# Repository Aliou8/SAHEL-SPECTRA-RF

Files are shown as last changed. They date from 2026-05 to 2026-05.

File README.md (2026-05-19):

# SAHEL-CUBESAT: An Experimental Educational CubeSat 
# Project work in progress

This project aims to develop a complete experimental CubeSat for educational purposes. It is based on an STM32H7 MCU for data handling and uses two CC1200 radios for communication. The software is developed using a Zephyr-like RTOS.

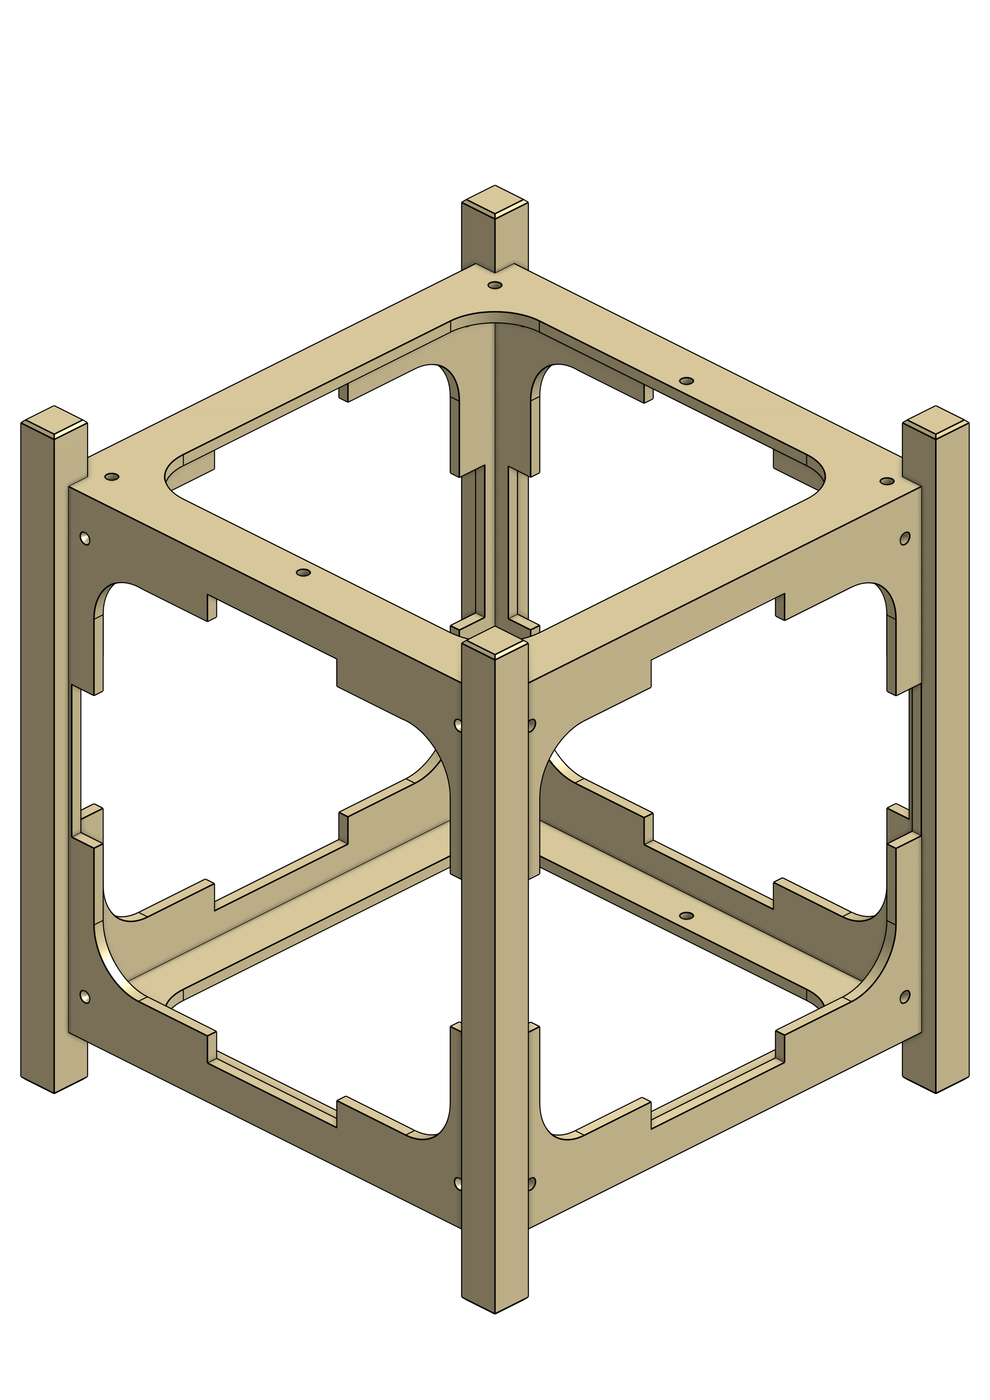
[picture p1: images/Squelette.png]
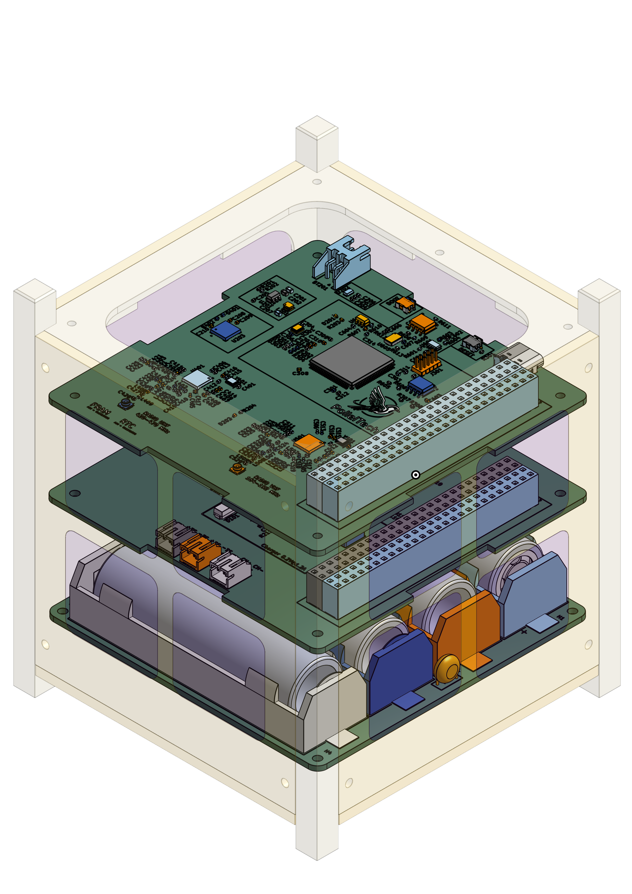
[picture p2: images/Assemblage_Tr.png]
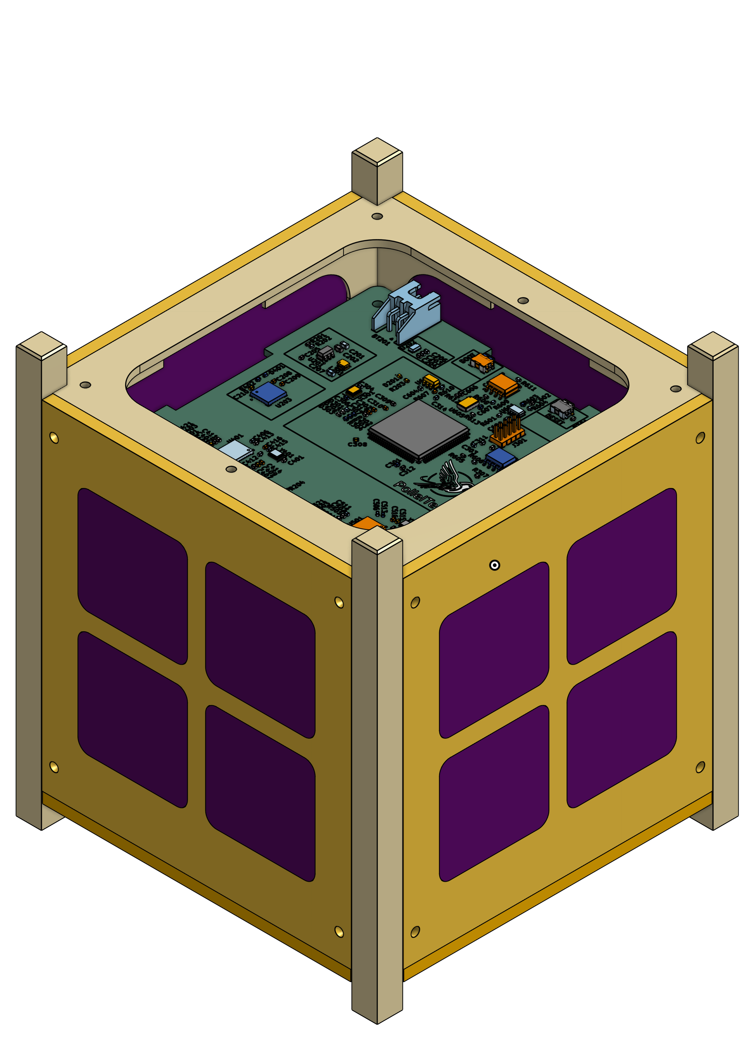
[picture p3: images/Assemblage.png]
<table>  <tr>    <td align="center">      <br>      <b>Mechanical Frame</b>    </td>    <td align="center">      <br>      <b>CubeSat Assembly with PCBs</b>    </td>    <td align="center">      <br>      <b>Complete CubeSat Assembly</b>    </td>  </tr></table>

## Table of Contents

- [Hardware](#hardware)
  - [Structure](#structure)
  - [Electronics](#electronics)
    - [Radio and OBC PCB](#radio-and-obc-pcb)
    - [Solar Panel and Battery PCB](#solar-panel-and-battery-pcb)

- [Software](#software)
  - [System Logic](#system-logic)
  - [Implementation](#implementation)

- [Ground Station Communication](#ground-station-communication)

---

## Hardware

### Structure

The structure was designed according to the specifications using [Onshape](https://cad.onshape.com?utm_source=chatgpt.com). All printable components can be found in this [directory](hardware/structure/).
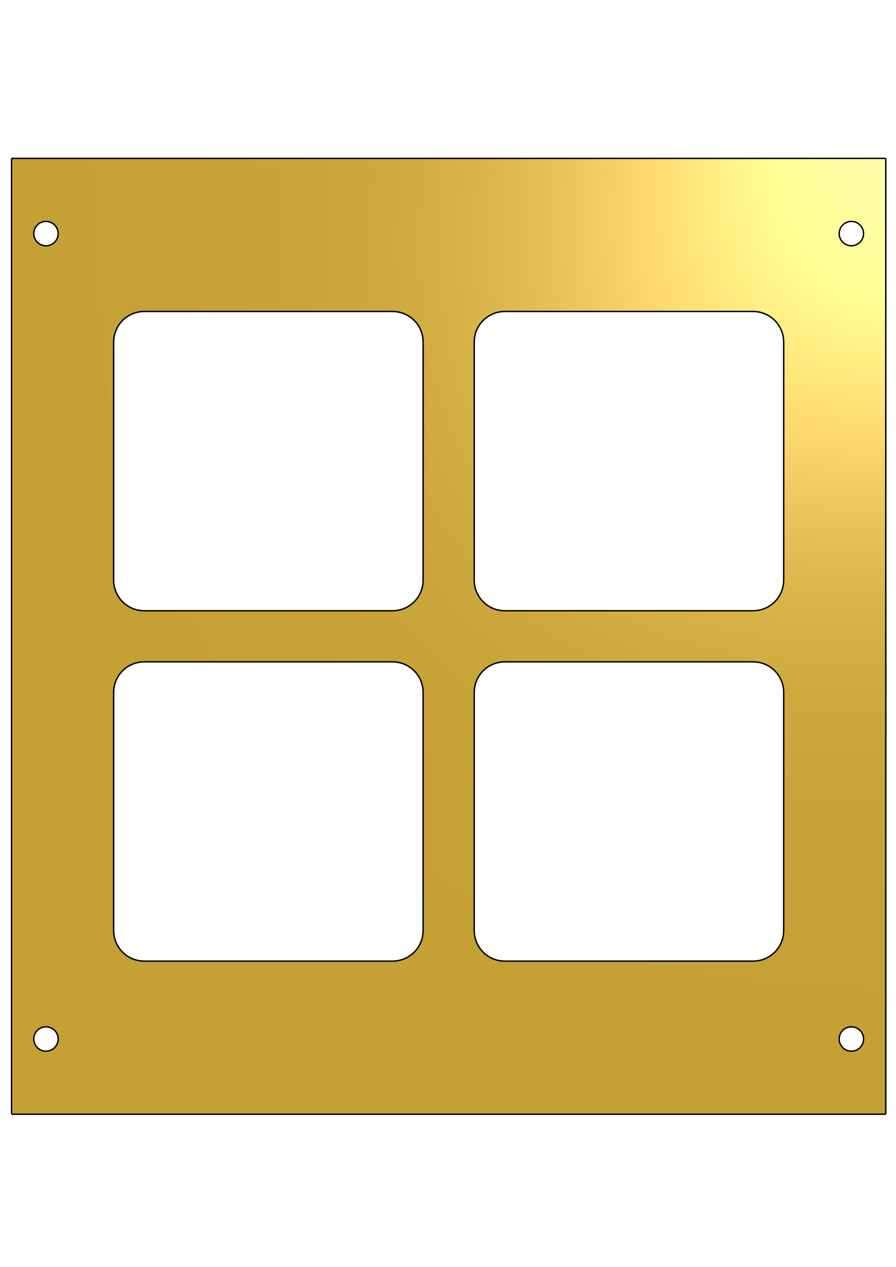
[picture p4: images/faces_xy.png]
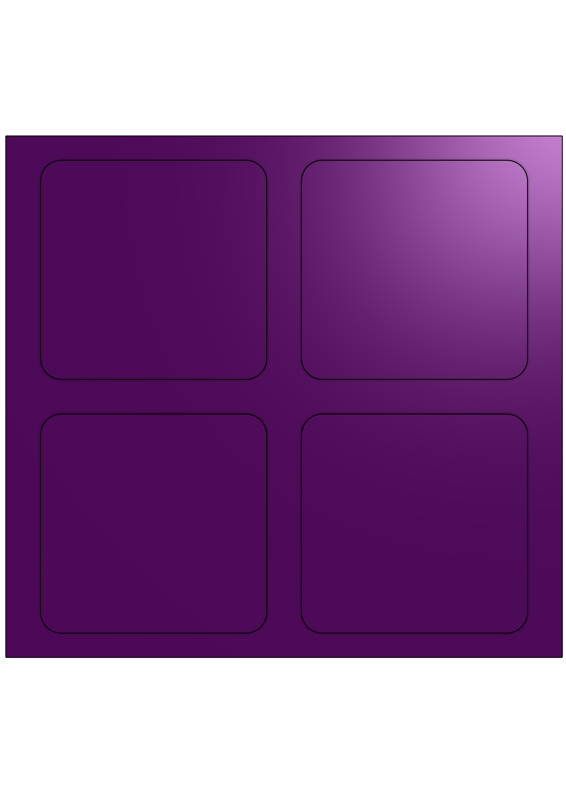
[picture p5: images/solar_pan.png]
<table>  <tr>    <td align="center">      <br>      <b>Mechanical faces X+ X- Y+ Y-</b>    </td>    <td align="center">      <br>      <b>Mechanical faces Z+ Z-</b>    </td>    <td align="center">      <br>      <b> Solar panel</b>    </td>  </tr></table>

---

### Electronics

KiCad is used for the electronic design. The hardware is divided into three parts. The first part includes the radio communication system and the OBC (On-Board Computer) for the CubeSat. The second part consists of a board integrating several sensors and a solar MPPT controller IC.

#### Radio and OBC PCB : Available in: [hardware/sahel_pcb_main](hardware/sahel_pcb_main/)

<table>
  <tr>
    <td align="center">
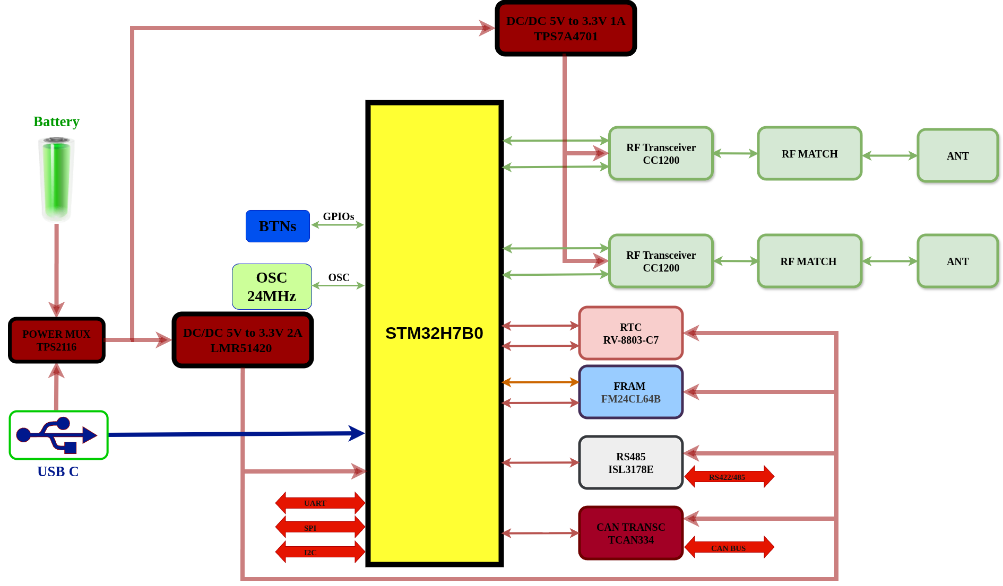
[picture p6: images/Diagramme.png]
      <br>
      <b>Architectural Diagram of the Radio and OBC PCB</b>
    </td>
    <td align="center">
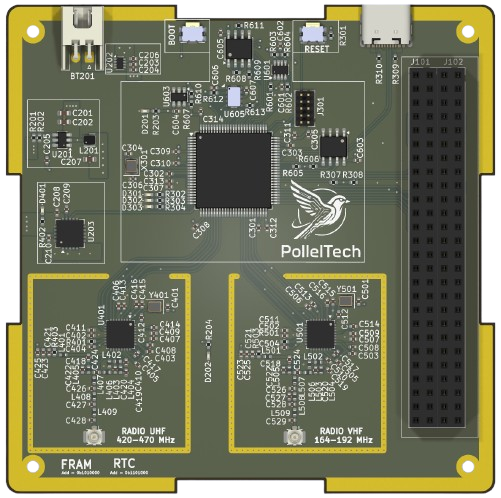
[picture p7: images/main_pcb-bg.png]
      <br>
      <b>Radio and OBC PCB</b>
    </td>
  </tr>
</table>

---

##### Components

###### MCU

**STM32H7B0VBTx**  
High-performance Arm Cortex-M7 MCU with DSP and DP-FPU, 128 KB Flash, 1,376 KB SRAM, up to 280 MHz.

---

###### FRAM — FM24CL64B

| Parameter | Value |
|---|---|
| Memory | 64-Kbit (8K × 8) |
| I2C Address | `0b1010000` |
| SDA (I2C3) | PC9 |
| SCL (I2C3) | PA8 |
| Write Protect | PC5 |

###### Sensors

**Accelerometer, Gyroscope, and Magnetometer: LSM9DS1**  
**Barometer: BMP388**

| Parameter | Value |
|---|---|
| I2C Address (ACC/GYRO) | `0b1101011` |
| I2C Address (MAG) | `0b0011110` |
| I2C Address (BARO) | `0b1110111` |
| SDA (I2C4) | PD13 |
| SCL (I2C4) | PD12 |
| INT_ACC/GYRO | PE8 |
| DRDY_MAG | PE7 |
| DRDY_BARO | PB2 |
---

###### RTC & Temperature Sensor

**RTC: RV-8803-C7**  
**TEMP: TMP100**

| Parameter | Value |
|---|---|
| RTC I2C Address  | `0b0110010` |
| TEMP I2C Address | `0b1001000` |
| SDA (I2C1) | PB7 |
| SCL (I2C1) | PB6 |
| RTC_INT | PB5 |
| RTC_EVI | PB4 |

---

###### CAN Interface: TCAN334G

| Signal | Pin  |
|---|---|
| CAN1_TX | PD1  |
| CAN1_RX | PD0  |
| CAN_SHDN | PA15 |
| CAN_STBY | PD2  |

---

###### RS-485 Interface: ISL3170E

| Signal | Pin  |
|---|---|
| UART2_RX | PD6  |
| UART2_TX | PD5  |
| UART2_EN | PD4  |

---
###### Radio Interface: CC1200

The CC1200 device is a fully integrated single-chip radio transceiver designed for high performance at very low-power and low-voltage operation in cost-effective wireless systems frequency bands at 164–192 MHz, 274–320 MHz, 410–480 MHz, and 820–960 MHz.

**UHF(TX/RX) 420-470 MHz**

| Signal | Pin  |
|---|---|
| UHF_SCK(SPI1) | PA5  |
| UHF_MISO(SPI1) | P6  |
| UHF_MOSI(SPI1) | P7  |
| UHF_CS(SPI1) | PA4  |
| UHF_GPIO2 | PC5  |
| UHF_GPIO3 | PC4  |

**VHF(TX/RX) 164-192 MHz**

| Signal | Pin  |
|---|---|
| UHF_SCK(SPI4) | PE12  |
| UHF_MISO(SPI4) | PE13  |
| UHF_MOSI(SPI4) | PE14  |
| UHF_CS(SPI4) | PE11  |
| UHF_GPIO2 | PB10  |
| UHF_GPIO3 | PE14  |

#### Solar Panel and Battery PCB

<table>
  <tr>
    <td align="center">
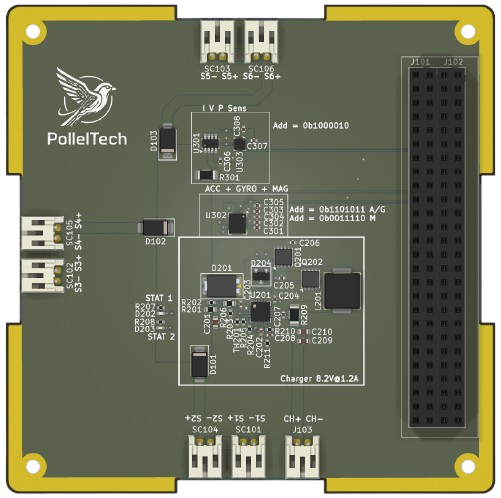
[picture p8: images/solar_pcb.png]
      <br>
      <b> Solar charger PCB </b>      
    </td>
    <td align="center">
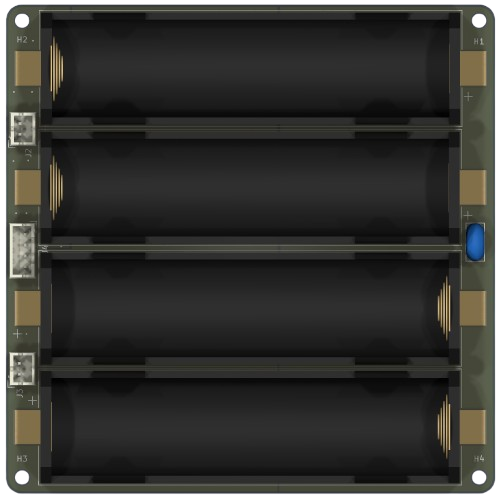
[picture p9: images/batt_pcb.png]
      <br>
      <b> Battery charger PCB </b>
    </td>
  </tr>
</table>

In this project, the BQ24650 solar charger is used together with an INA219A current sensor for photovoltaic (IPV) monitoring.

| Parameter | Value |
|---|---|
| Input Voltage (Vin) | 9V – 24V |
| MPPT Voltage (VMPPT) | 9V |
| Charge Voltage | 8.2V |
| Charge Current | 1.2A |
| Precharge Current | 125mA |
| Termination Current | 125mA |
| INA219A I2C Address | `0b1000010` |
| SDA (I2C4) | PD13 |
| SCL (I2C4) | PD12 |

---

### Battery Pack & Protection

The system uses four RS PRO Li-Ion batteries configured in a 2S2P arrangement with the following specifications:

| Parameter | Value |
|---|---|
| Nominal Voltage | 3.60V |
| Capacity | 3500mAh |
| Maximum Charge Voltage | 4.20V |
| Energy | 12.60Wh |
| Operating Voltage | 4.20V – 2.50V |
| Cut-Off Voltage | 2.50V |
| Standard Charge Method | CC-CV |
| Standard Charge Current | 0.2C (0.7A) |
| Standard Charge Cut-Off Current | 0.02C (0.07A) |
| Maximum Continuous Charge Current | 1.0C (3.5A) |

#### Standard Discharge Conditions

| Temperature Range | Discharge Current |
|---|---|
| 0°C – 10°C | 0.1C (0.35A) |
| 10°C – 20°C | 0.2C (0.7A) |
| 20°C – 45°C | 0.5C (1.75A) |

The battery protection and monitoring system is based on the BQ76907 battery monitor IC and an INA219A current sensor.

| Parameter | Value |
|---|---|
| I2C Address (BQ76907) | `0b0001000` (default) |
| I2C Address (INA219A) | `0b1000000` |
| SDA (I2C1) | PB7 |
| SCL (I2C1) | PB6 |
| Battery Alert | PE2 |

---

## Software

The software is developed using **Zephyr RTOS**.  
The middleware architecture is described in the [Software Documentation](software/README.md).

---

## System Logic

We are developing the system based on **Zephyr RTOS**, using a **multi-threaded architecture** combined with **Zephyr zbus** for internal communication.

The application is structured around multiple independent threads that communicate through the **zbus message bus system**.

### Key concepts:
- Each module acts as a **zbus publisher and/or subscriber**
- Data is exchanged through **well-defined channels**
- This avoids tight coupling between components
- Improves scalability and modularity of the system

### Benefits of using zbus:
- Decoupled architecture between threads
- Clean publish/subscribe communication model
- Easier debugging and tracing of data flow
- Better maintainability for complex systems

---

## Ground Station Communication

The ground station software is **not yet implemented**.  
The current plan is to develop it using either:
- **Qt-based applications** (for a custom GUI control station)
- or existing **SDR software tools** for signal reception and analysis

---

## Communication Mechanism

The communication between the system and the ground station is designed around a structured and layered protocol stack.

### 1. Physical & Link Layer
The system uses the **AX.25 protocol** as the primary data link layer.

AX.25 provides:
- reliable packet framing
- addressing capability (callsigns)
- error detection (CRC)
- compatibility with amateur radio / SDR systems

---

### 2. Packet Structure

All exchanged data is encapsulated in AX.25 frames containing:
- payload data
- message type identifier
- optional sequence number
- checksum (handled by AX.25 layer)

---

### 3. Command System

The ground station can send **commands** to the embedded system.

Commands are structured as:
- command ID
- optional parameters
- target module (if applicable)

Examples of command types:
- system control (start / stop / reset)
- configuration update
- request sensor data
- debug / diagnostics requests

---

### 4. Internal Routing (zbus integration)

Incoming and outgoing messages are bridged into the internal **zbus architecture**.

Flow:
- AX.25 frame received → decoded → converted to internal message
- message published on **zbus channel**
- relevant modules subscribe and react

---

### 5. Response System

The system responds using structured messages:
- ACK / NACK for command validation
- telemetry data packets
- event notifications
- status reports

All responses follow the same pipeline:
**zbus → encoder → AX.25 → ground station**

---

### 6. Design Goals

This architecture is designed to ensure:
- robustness over noisy RF links
- modular separation between communication and logic
- easy integration with SDR tools
- future compatibility with different ground station implementations

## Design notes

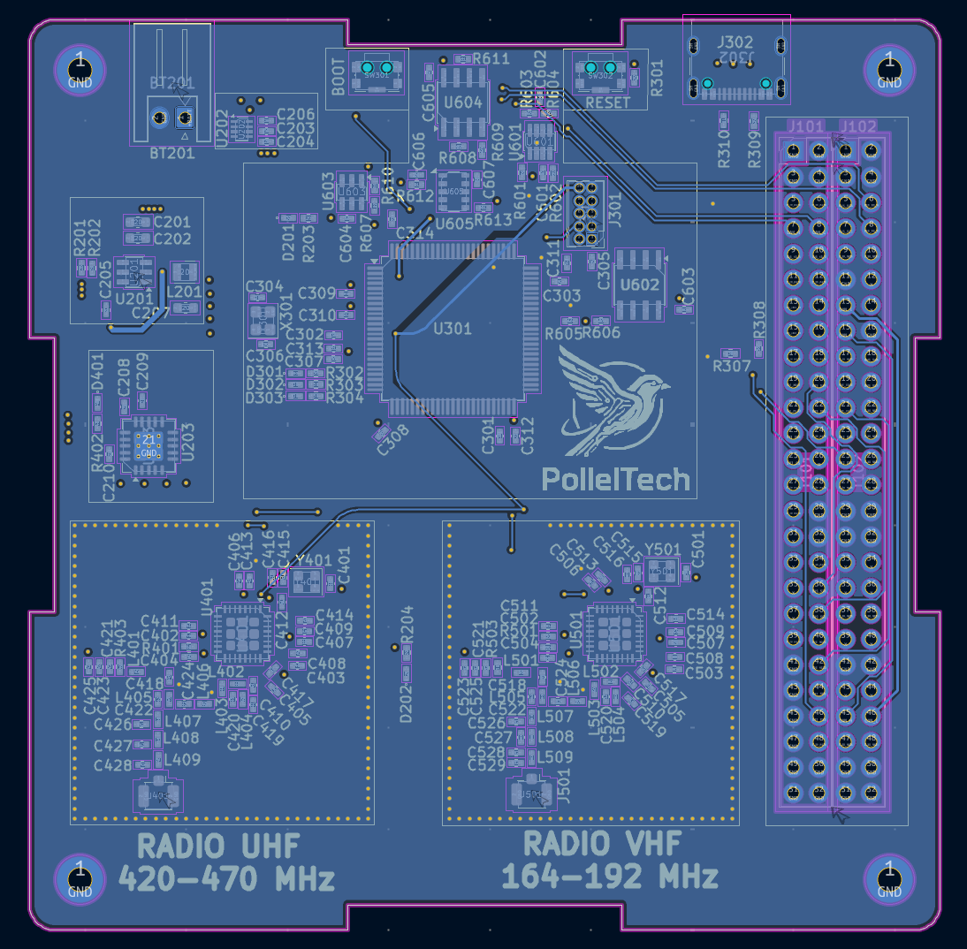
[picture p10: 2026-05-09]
images/BCU.png

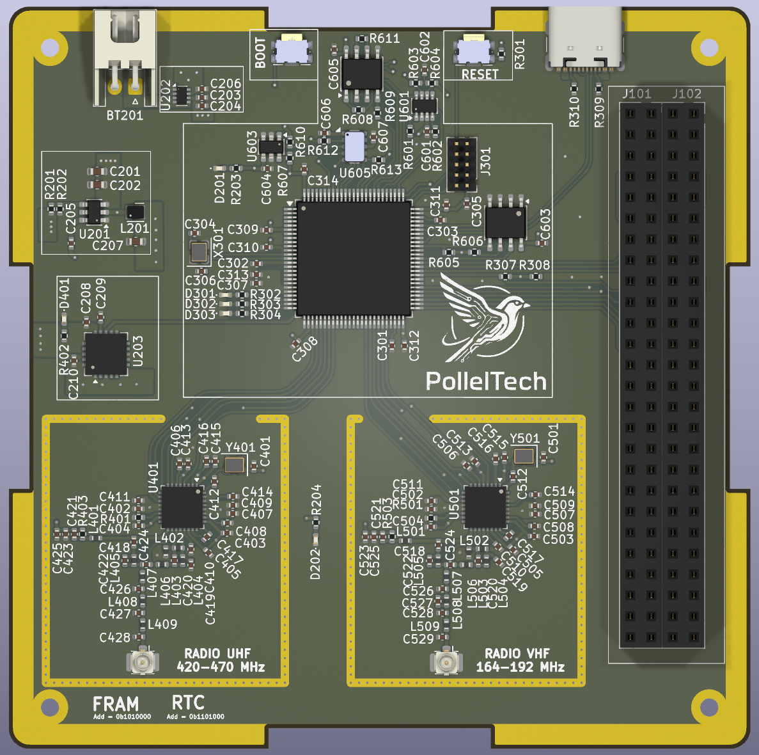
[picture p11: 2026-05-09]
images/main_pcb.png

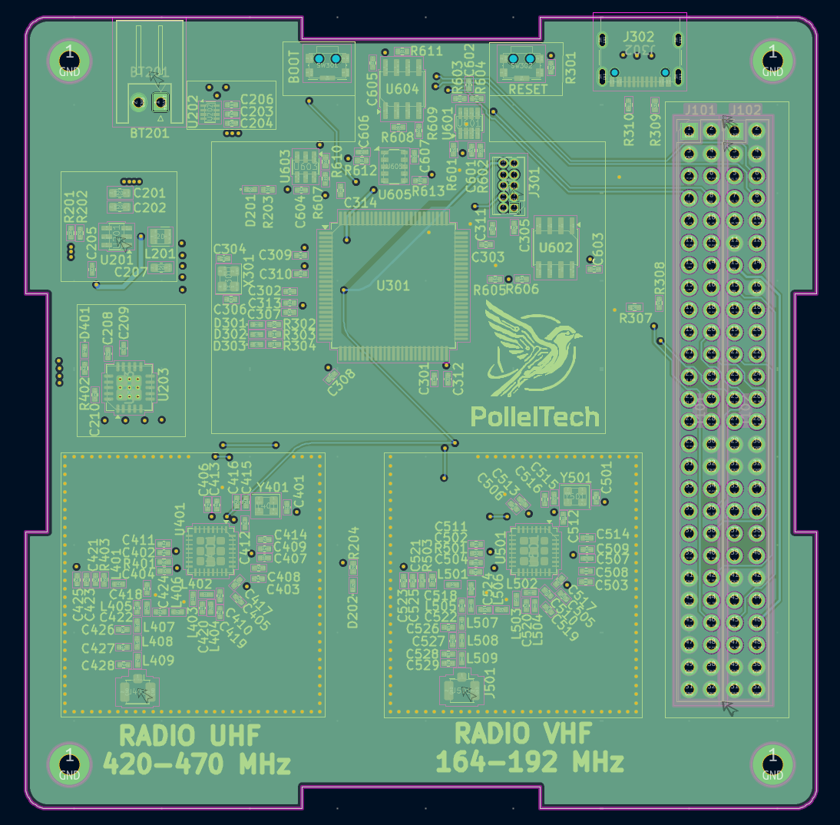
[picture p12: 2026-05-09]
images/L2.png

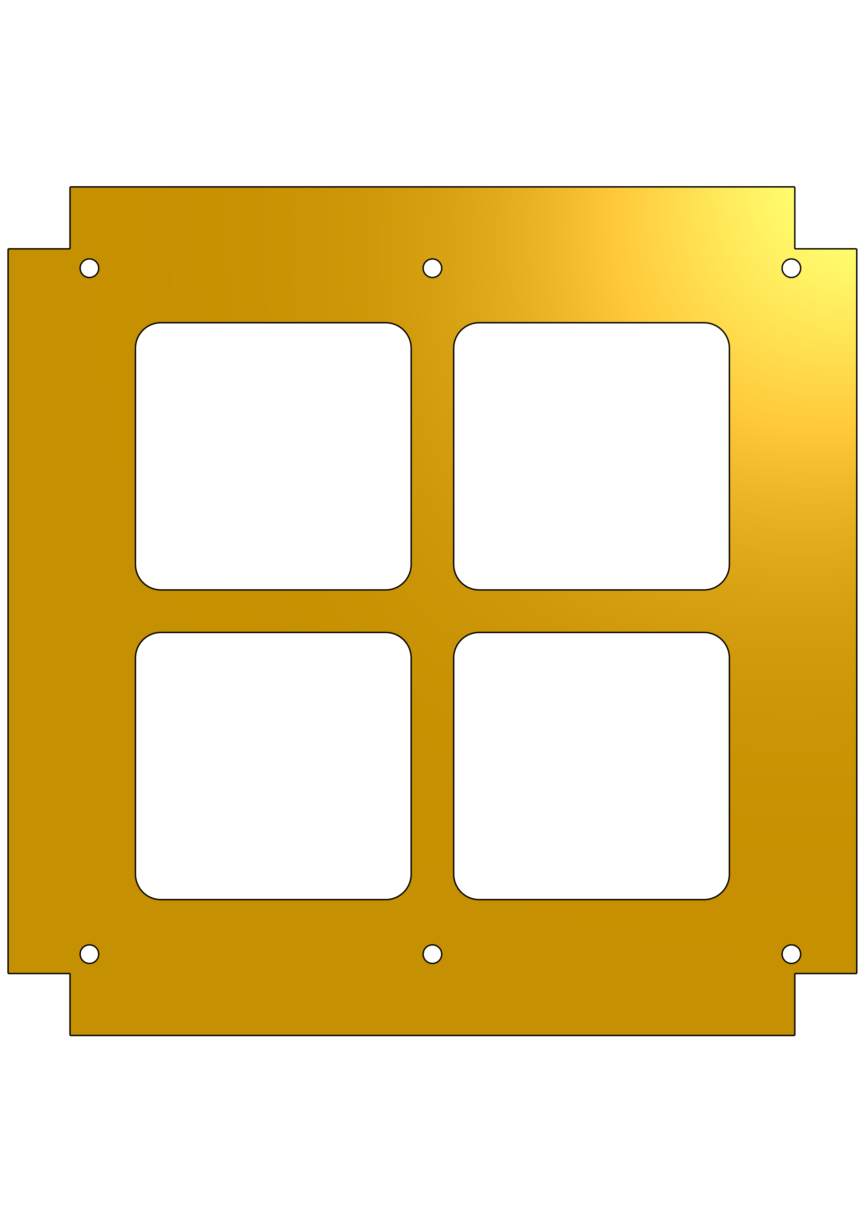
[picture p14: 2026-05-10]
images/faces_z.png

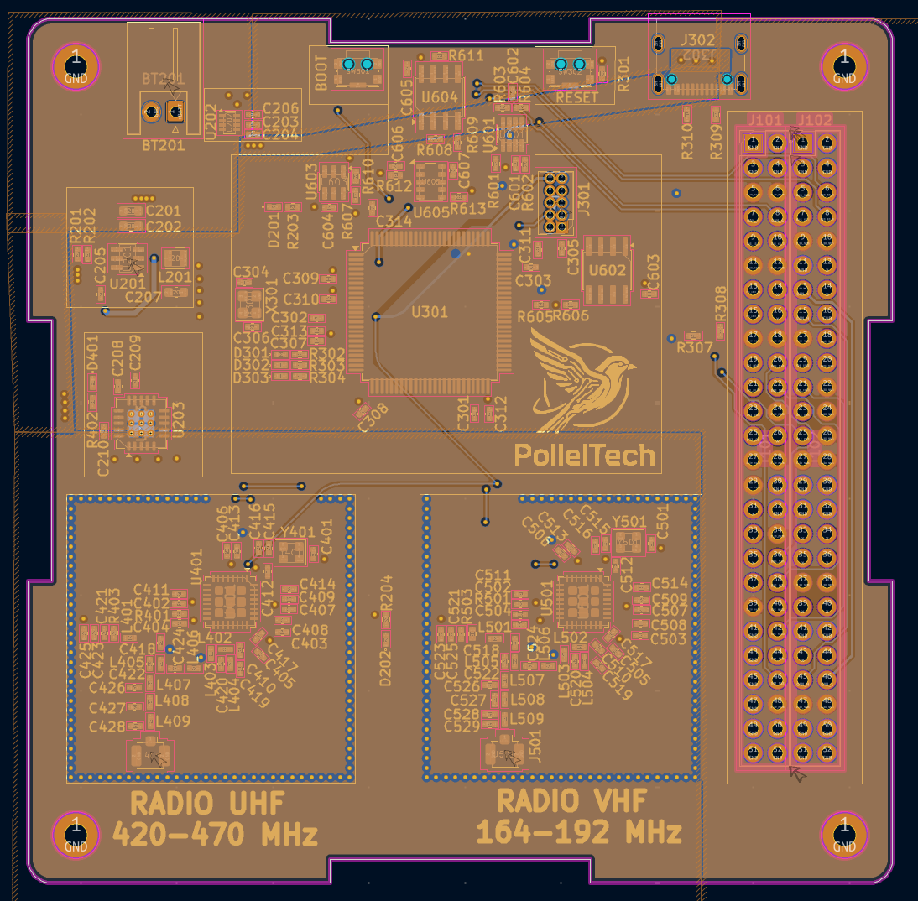
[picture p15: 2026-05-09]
images/L3.png

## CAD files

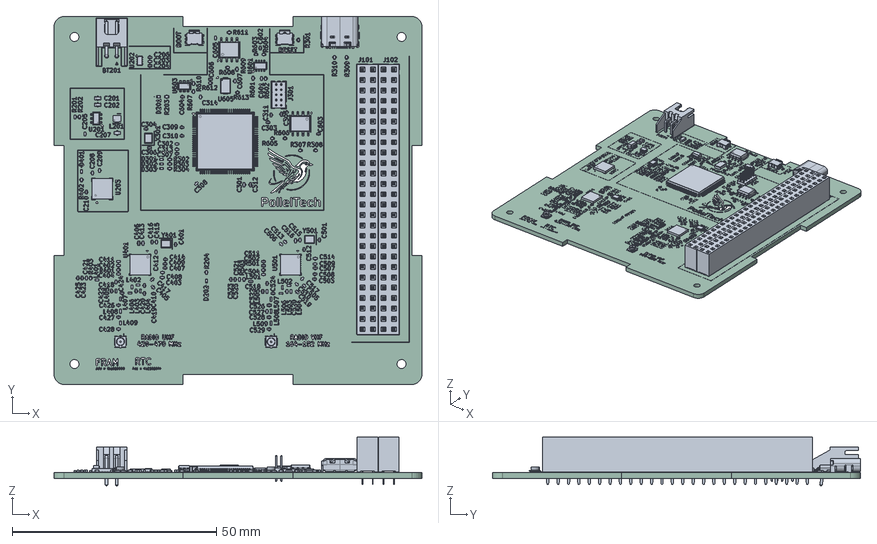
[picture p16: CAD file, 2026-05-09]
hardware/3D/main_PCB.STEP
90.0 x 90.0 x 11.9 mm
R_0402_1005Metric x 30
C_0402_1005Metric x 85
L_0402_1005Metric x 18
PinHeader_2x05_P1.27mm_Vertical
SOT-583-8
LED_0402_1005Metric x 6
C_0603_1608Metric x 3
U.FL_Hirose_U.FL-R-SMT-1_Vertical x 2
KMS2x1GPxxx x 2
TSOT-23-8
RV-8523-C3-TA-QC-020
QFN-32-1EP_5x5mm_P0.5mm_EP3.45x3.45mm x 2
PinSocket_2x26_P2.54mm_Vertical x 2
SOIC-8_3.9x4.9mm_P1.27mm x 2
Crystal_SMD_2520-4Pin_2.5x2.0mm
Crystal_SMD_WE_CFPX-218-4Pin_2.5x2.0mm x 2
SOT-23-6 x 2
L_Wurth_WE-LQSH-2010
LQFP-100_14x14mm_P0.5mm
USB_C_Receptacle_GCT_USB4105-xx-A_16P_TopMnt_Horizontal
Texas_RGW0020A_VQFN-20-1EP_5x5mm_P0.65mm_EP3.15x3.15mm
JST_XH_S2B-XH-A_1x02_P2.50mm_Horizontal
sahel_pcb_silkscreen
sahel_pcb_PCB

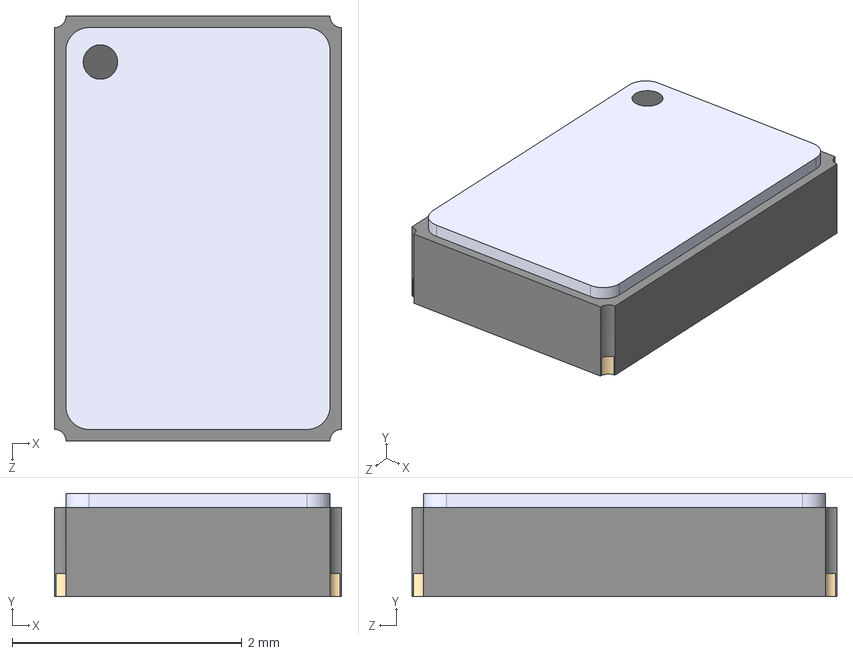
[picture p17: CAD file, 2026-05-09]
hardware/3D/RV-8523-C3-TA-QC-020.STEP
2.50 x 0.9 x 3.70 mm

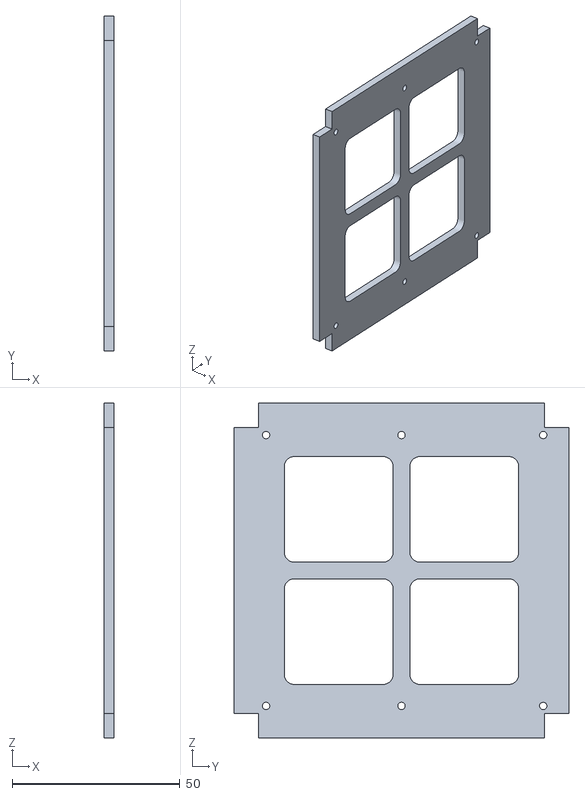
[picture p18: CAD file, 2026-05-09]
hardware/structure/faces_z.stl
3.00 x 100.0 x 100.0

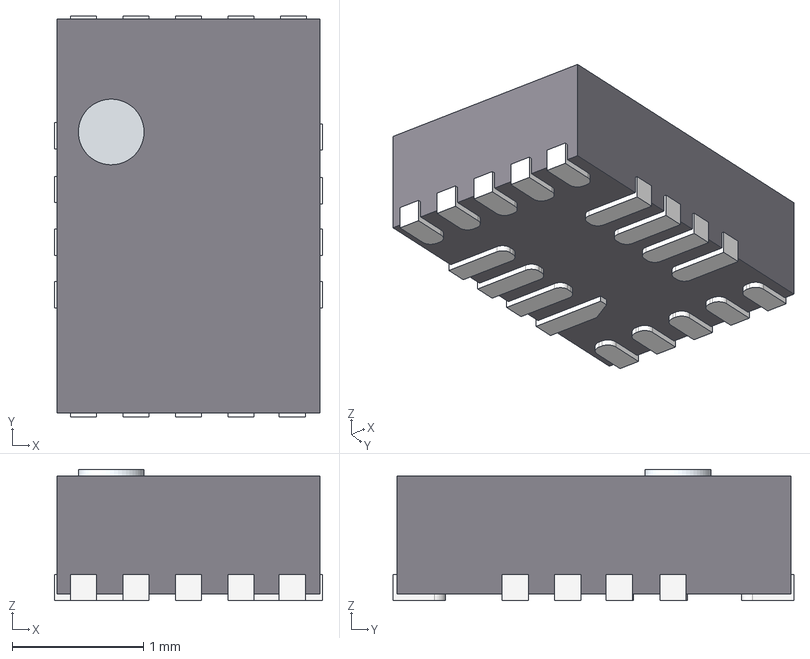
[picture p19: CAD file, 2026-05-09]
hardware/3D/QFN18_2mmx3mm_model.step
2.04 x 3.05 x 1.00 mm
Pin1-IndexPad
Pin2-LongPad
Pin3-LongPad
Pin4-LongPad
Pin5-ShortPad
Pin6-ShortPad
Pin7-ShortPad
Pin8-ShortPad
Pin9-ShortPad
Pin10-LongPad
Pin11-LongPad
Pin12-LongPad
Pin13-LongPad
Pin14-ShortPad
Pin15-ShortPad
Pin16-ShortPad
Pin17-ShortPad
Pin18-ShortPad
CopyPart__Feature

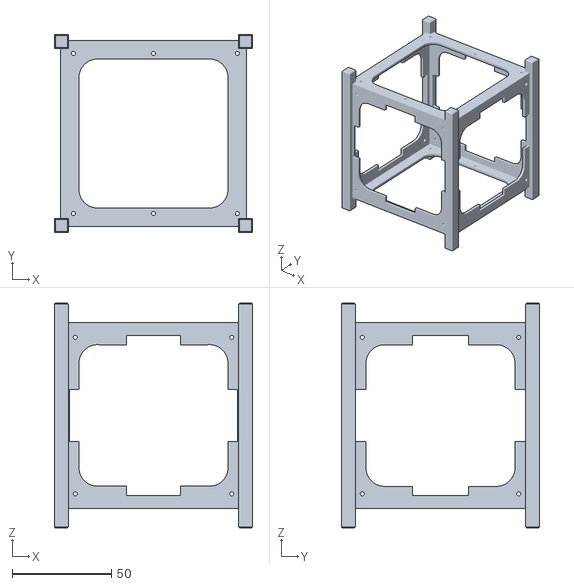
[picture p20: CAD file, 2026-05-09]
hardware/structure/Squelette.stl
100.0 x 100.0 x 113.5

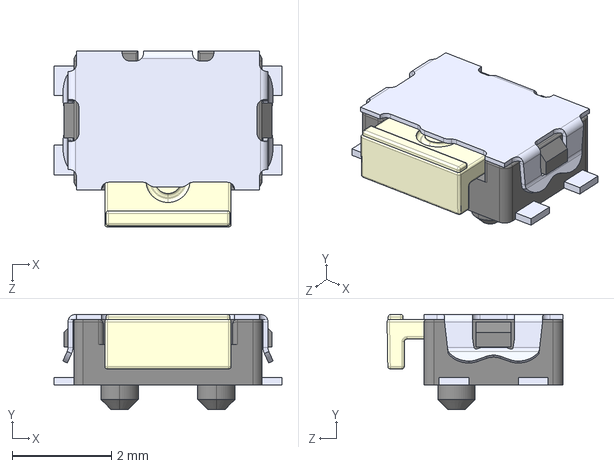
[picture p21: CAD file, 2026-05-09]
hardware/3D/KMS231GPLFS.STEP
4.60 x 1.92 x 3.55 mm

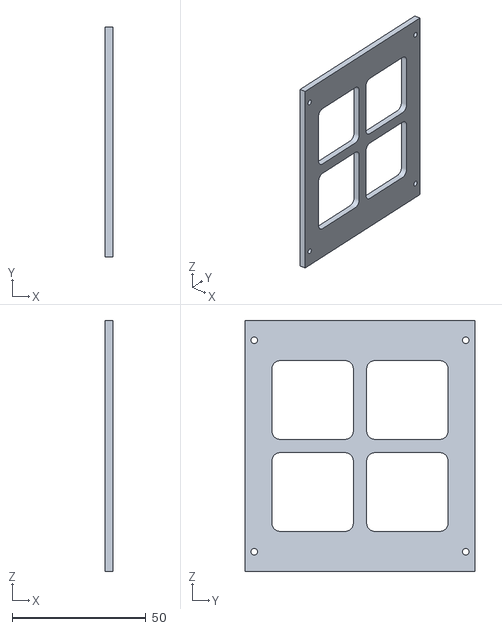
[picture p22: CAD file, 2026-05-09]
hardware/structure/faces_xy.stl
3.00 x 85.7 x 93.7

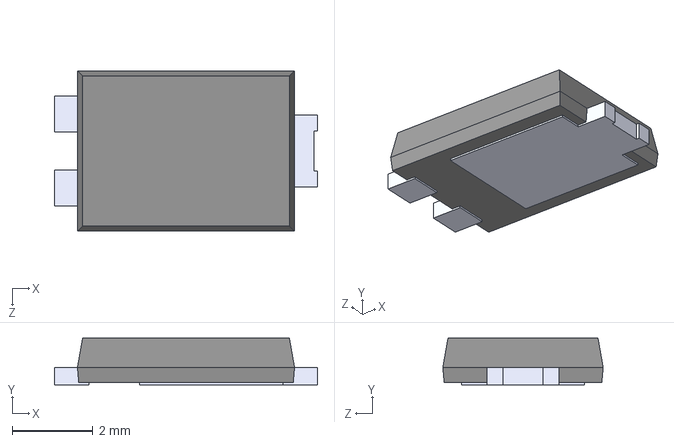
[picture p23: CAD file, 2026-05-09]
hardware/3D/PDS3100Q-13.STEP
6.50 x 1.15 x 3.97 mm

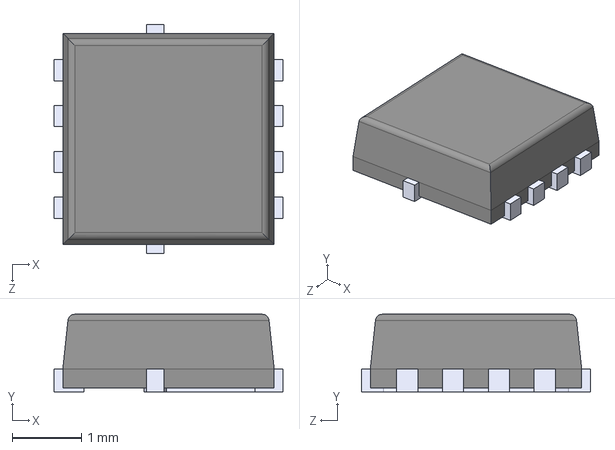
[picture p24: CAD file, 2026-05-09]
hardware/3D/SIS454DN-T1-GE3.STEP
3.30 x 1.12 x 3.30 mm

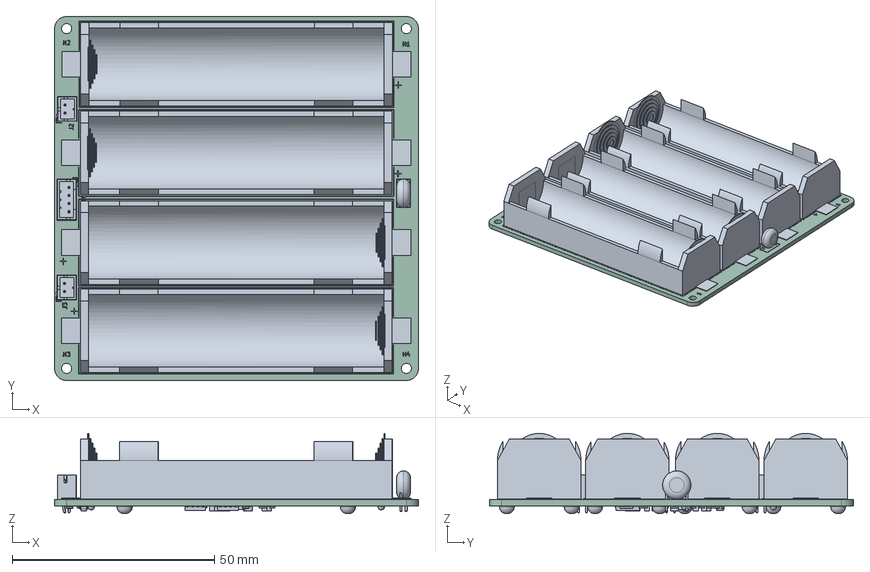
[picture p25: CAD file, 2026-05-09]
hardware/3D/solar_PCB.STEP
90.0 x 90.0 x 19.8 mm
JST_PH_B4B-PH-K_1x04_P2.00mm_Vertical
RV_Disc_D7mm_W3.4mm_P5mm
BatteryHolder_Keystone_1042_1x18650 x 4
JST_PH_B2B-PH-K_1x02_P2.00mm_Vertical x 2
R_0805_2012Metric x 10
C_0805_2012Metric x 9
SOT-323_SC-70 x 2
Texas_VQFN-RGR-20-1EP_3.5x3.5mm_Pitch0.5mm
R_1206_3216Metric x 2
SOT-23-8
C_0402_1005Metric x 2
TDSON-8-1 x 2
sahel_battery_silkscreen x 2
sahel_battery_PCB

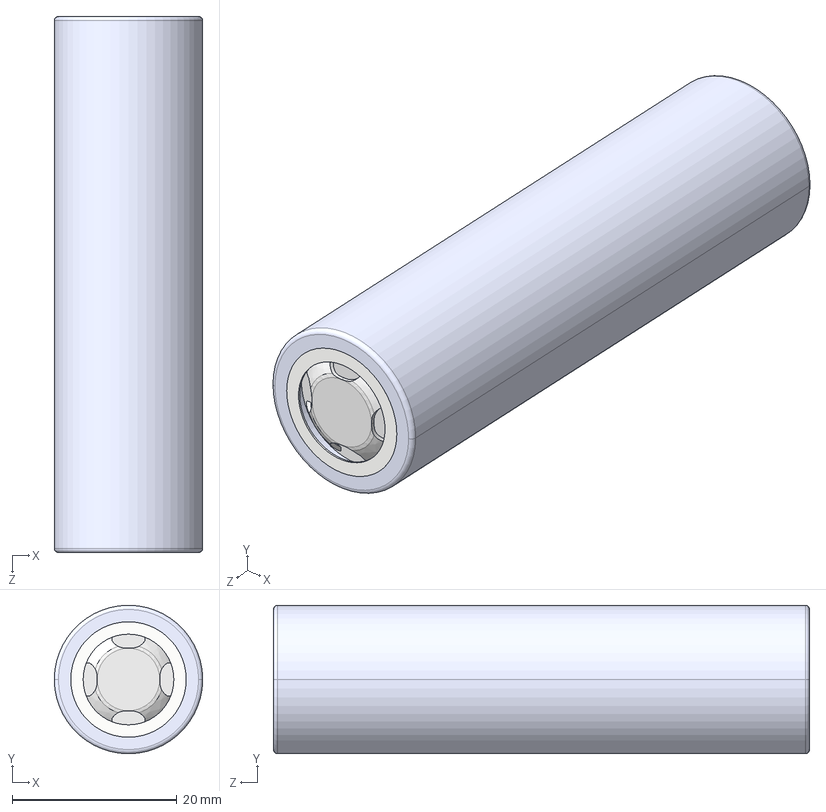
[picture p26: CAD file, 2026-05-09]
hardware/3D/Cell 18650.STEP
18.0 x 18.0 x 65.0 mm
battery 186501^battery 18650(2)_battery 18650
battery 186502^battery 18650(2)_battery 18650
battery 186503^battery 18650(2)_battery 18650
battery 186504^battery 18650(2)_battery 18650

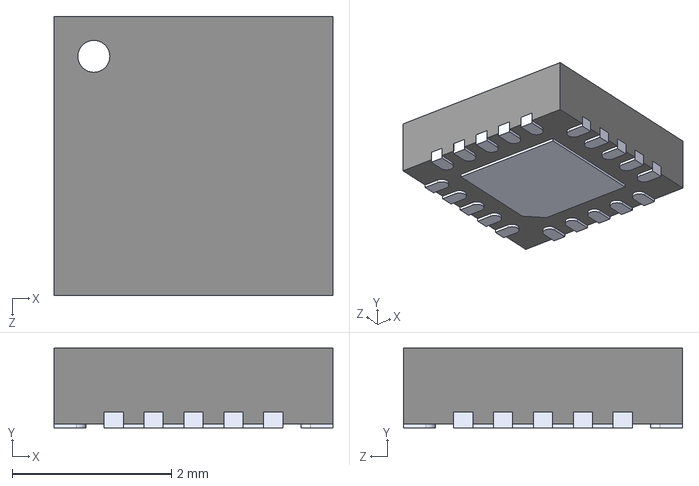
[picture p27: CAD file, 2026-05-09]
hardware/3D/BQ76907RGRR.STEP
3.50 x 1.00 x 3.50 mm

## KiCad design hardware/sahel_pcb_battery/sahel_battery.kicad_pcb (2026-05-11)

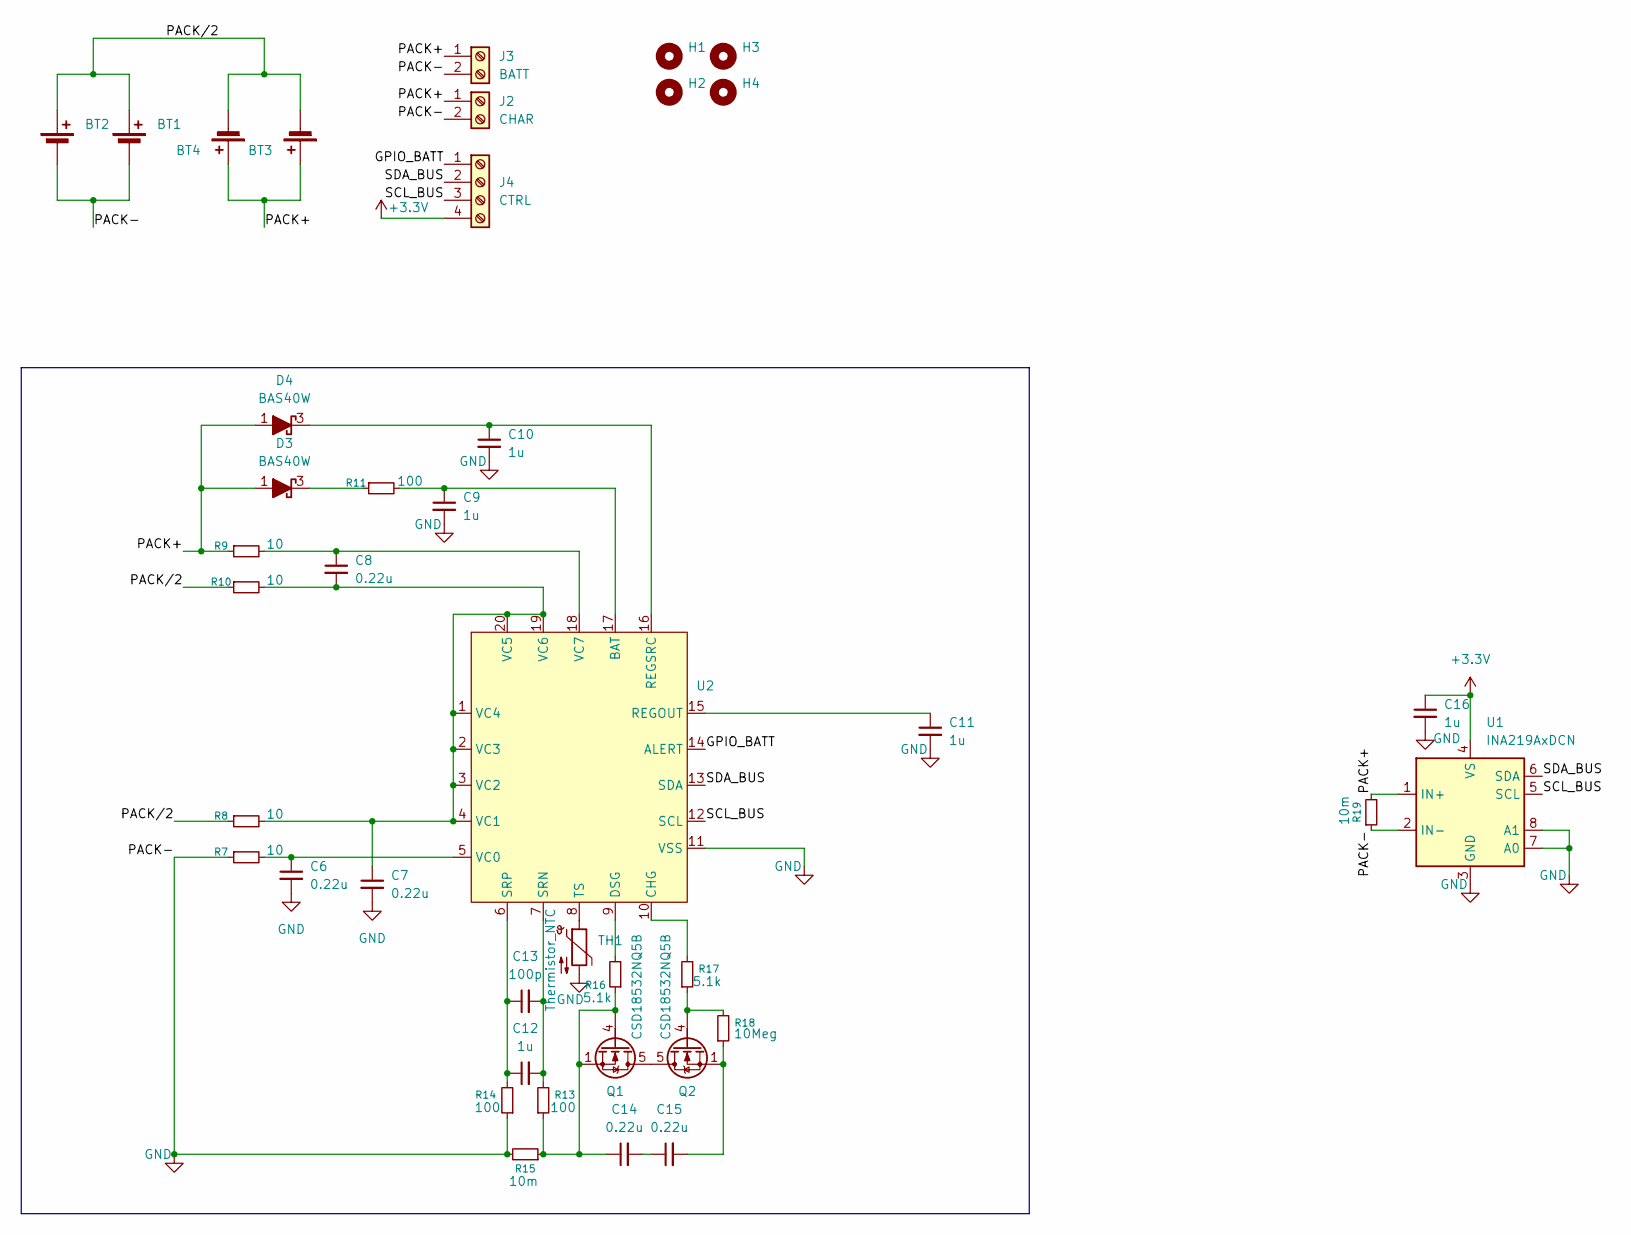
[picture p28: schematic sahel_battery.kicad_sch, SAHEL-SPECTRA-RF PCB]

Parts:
BT1, BT2, BT3, BT4: Battery_Cell; BatteryHolder_Keystone_1042_1x18650
C6, C7, C8, C14, C15: 0.22u; C_0805_2012Metric
C9, C10, C12: 1u; C_0805_2012Metric
C11, C16: 1u; C_0402_1005Metric
C13: 100p; C_0805_2012Metric
D3, D4: BAS40W; SOT-323_SC-70
H1, H2, H3, H4: MountingHole; MountingHole_2.5mm
J2: CHAR; JST_PH_B2B-PH-K_1x02_P2.00mm_Vertical
J3: BATT; JST_PH_B2B-PH-K_1x02_P2.00mm_Vertical
J4: CTRL; JST_PH_B4B-PH-K_1x04_P2.00mm_Vertical
Q1, Q2: CSD18532NQ5B; TDSON-8-1
R7, R8, R9, R10: 10; R_0805_2012Metric
R11, R13, R14: 100; R_0805_2012Metric
R15, R19: 10m; R_1206_3216Metric
R16, R17: 5.1k; R_0805_2012Metric
R18: 10Meg; R_0805_2012Metric
TH1: Thermistor_NTC; RV_Disc_D7mm_W3.4mm_P5mm
U1: INA219AxDCN; SOT-23-8
U2: QFN-20-1EP_3.5x3.5mm_P0.5mm_EP2x2mm

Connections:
+3.3V: C16.1, J4.4, U1.4 (VS)
/GPIO_BATT: J4.1, U2.14 (ALERT)
/PACK+: BT3.1 (+), BT4.1 (+), D3.1 (A), D4.1 (A), J2.1, J3.1, R9.1, R19.2, U1.1 (IN+)
/PACK/2: BT1.1 (+), BT2.1 (+), BT3.2 (-), BT4.2 (-), R8.1, R10.1
/SCL_BUS: J4.3, U1.5 (SCL), U2.12 (SCL)
/SDA_BUS: J4.2, U1.6 (SDA), U2.13 (SDA)
GND: BT1.2 (-), BT2.2 (-), C6.2, C7.2, C9.2, C10.2, C11.2, C16.2, J2.2, J3.2, R7.1, R14.1, R15.2, R19.1, TH1.2, U1.2 (IN-), U1.3 (GND), U1.7 (A0), U1.8 (A1), U2.11 (VSS), U2.21 (PAD)
unnamed: C14.2, C15.1
unnamed: C15.2, Q2.1 (S), Q2.2 (S), Q2.3 (S), R18.1
unnamed: D3.3 (K), R11.1
unnamed: C10.1, D4.3 (K), U2.16 (REGSRC)
unnamed: Q1.5 (D), Q2.5 (D)
unnamed: C14.1, Q1.1 (S), Q1.2 (S), Q1.3 (S), Q1.4 (G), R13.1, R15.1, R16.1
unnamed: Q2.4 (G), R17.1, R18.2
unnamed: C9.1, R11.2, U2.17 (BAT)
unnamed: R17.2, U2.10 (CHG)
unnamed: R16.2, U2.9 (DSG)
unnamed: C11.1, U2.15 (REGOUT)
unnamed: C12.2, C13.2, R13.2, U2.7 (SRN)
unnamed: C12.1, C13.1, R14.2, U2.6 (SRP)
unnamed: TH1.1, U2.8 (TS)
unnamed: C6.1, R7.2, U2.5 (VC0)
unnamed: C7.1, C8.2, R8.2, R10.2, U2.1 (VC4), U2.2 (VC3), U2.3 (VC2), U2.4 (VC1), U2.19 (VC6), U2.20 (VC5)
unnamed: C8.1, R9.2, U2.18 (VC7)

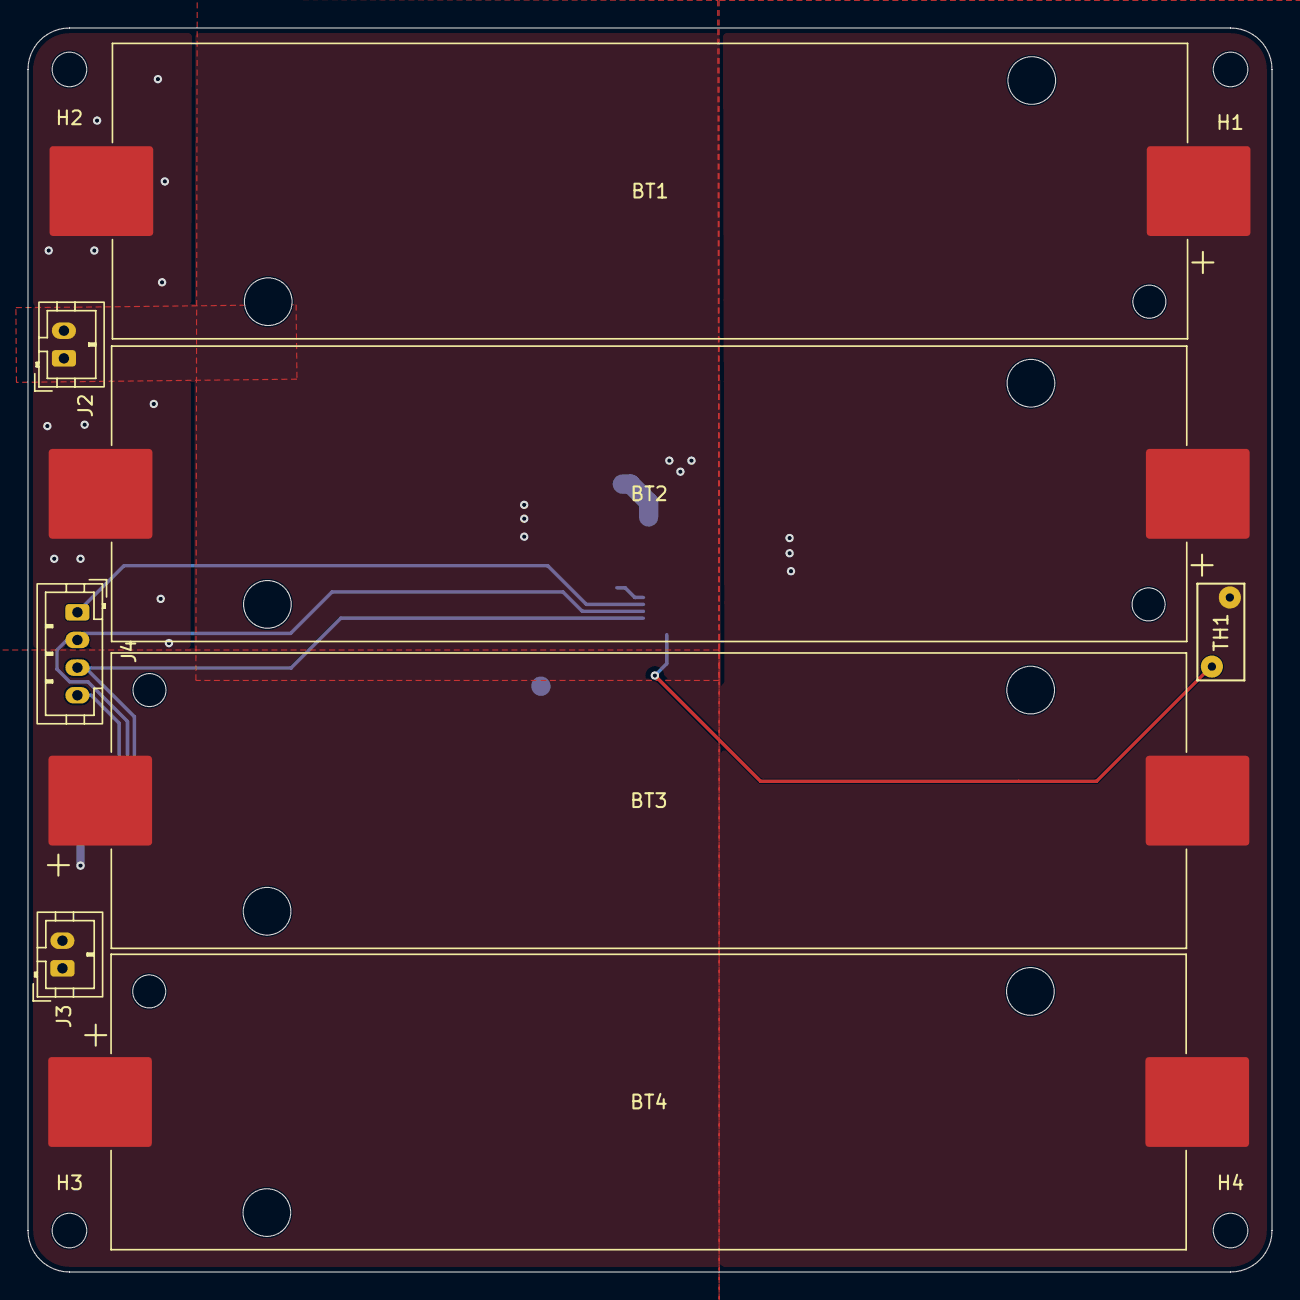
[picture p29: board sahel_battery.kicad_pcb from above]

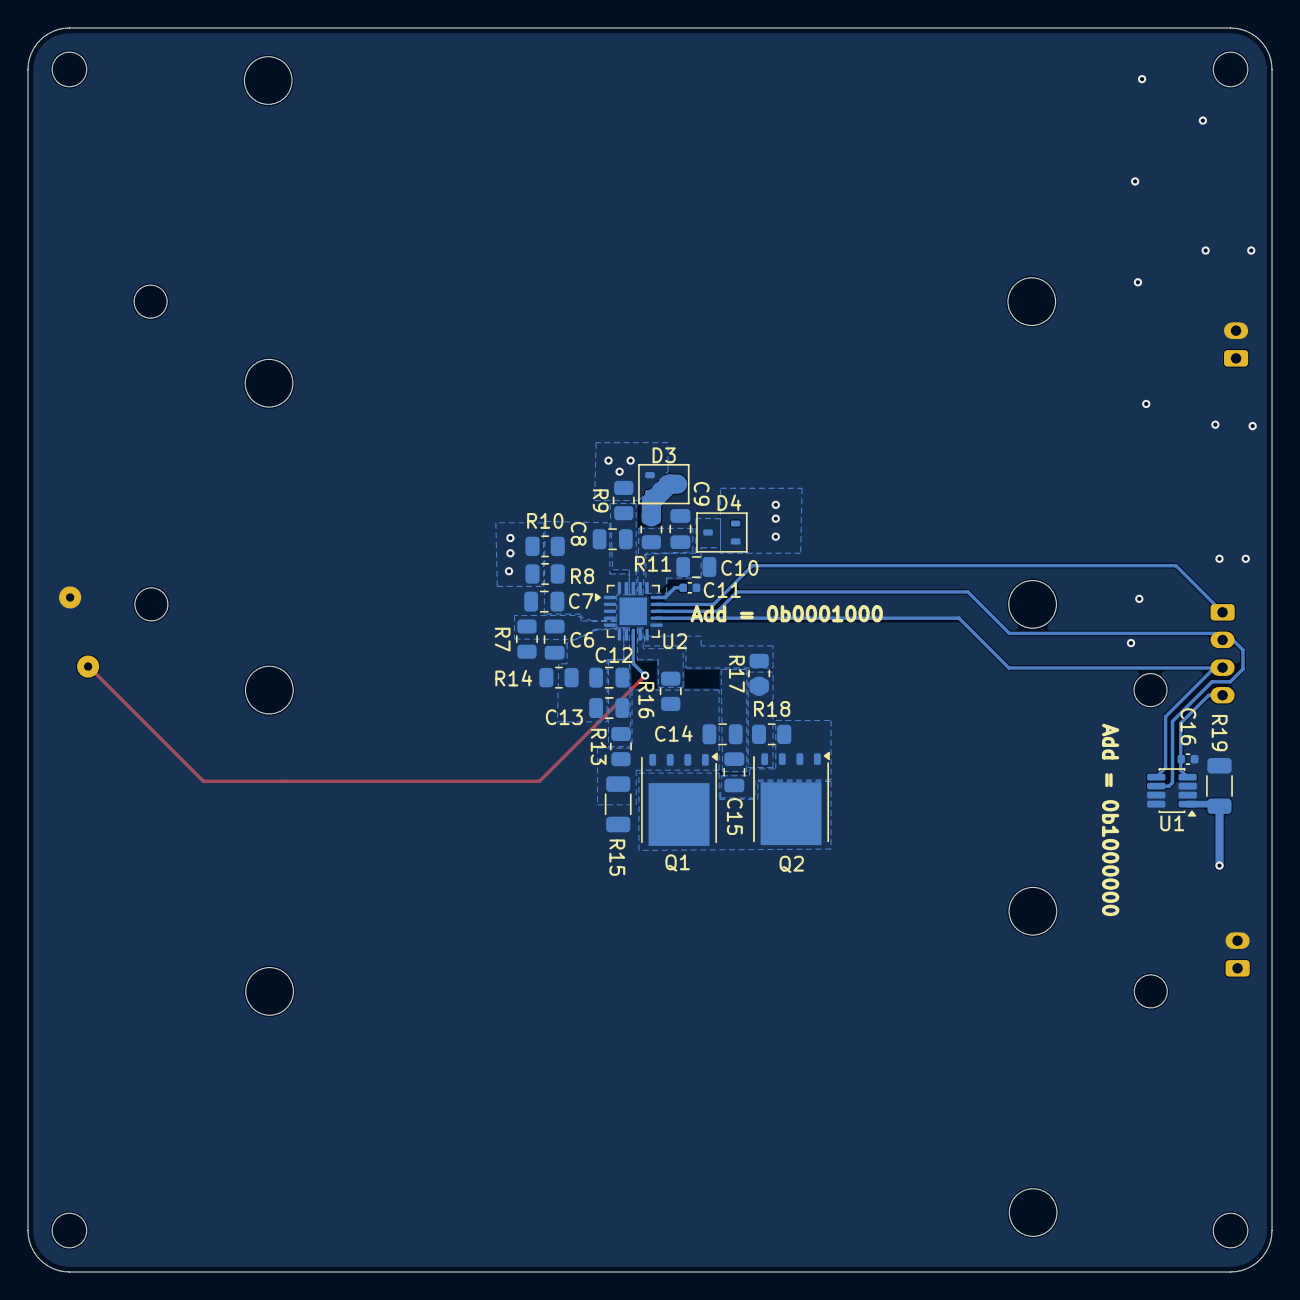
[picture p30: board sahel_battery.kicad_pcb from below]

Board: 2 copper layers, 90.0 x 90.0 mm, 41 parts (29 on the bottom side), 24 nets.

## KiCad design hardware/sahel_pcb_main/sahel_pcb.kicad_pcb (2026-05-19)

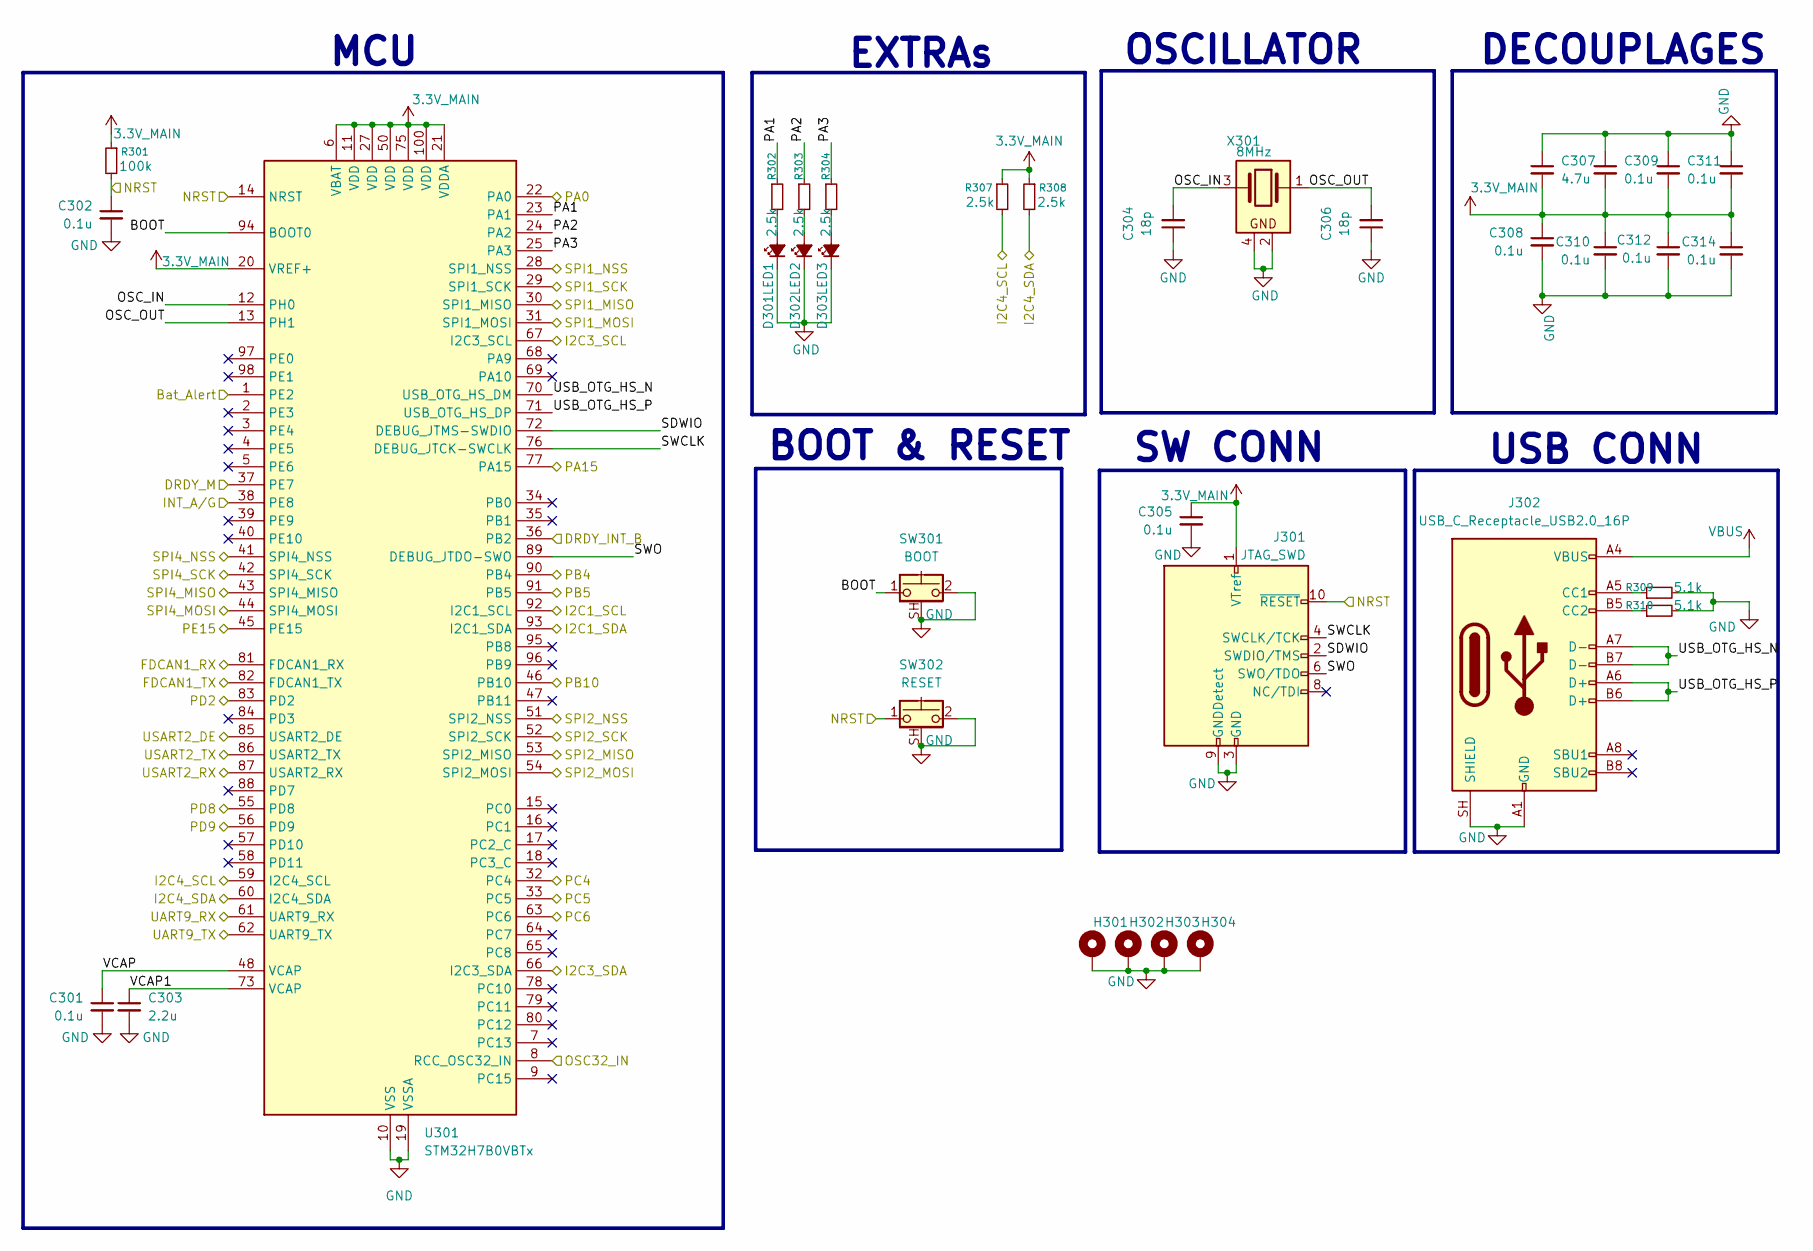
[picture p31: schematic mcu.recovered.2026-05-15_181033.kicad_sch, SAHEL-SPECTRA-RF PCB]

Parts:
C301, C302, C305, C308, C309, C310, C311, C312, C313, C314: 0.1u; C_0402_1005Metric
C303: 2.2u; C_0402_1005Metric
C304, C306: 18p; C_0402_1005Metric
C307: 4.7u; C_0402_1005Metric
D301: LED1; LED_0402_1005Metric
D302: LED2; LED_0402_1005Metric
D303: LED3; LED_0402_1005Metric
H301, H302, H303, H304: MountingHole_Pad; MountingHole_2.2mm_M2_Pad
J301: JTAG_SWD; PinHeader_2x05_P1.27mm_Vertical
J302: USB_C_Receptacle_USB2.0_16P; USB_C_Receptacle_GCT_USB4105-xx-A_16P_TopMnt_Horizontal
R301: 100k; R_0402_1005Metric
R302, R303, R304, R307, R308: 2.5k; R_0402_1005Metric
R309, R310: 5.1k; R_0402_1005Metric
SW301: BOOT; SW_SPST_CK_KMS2xxGP
SW302: RESET; SW_SPST_CK_KMS2xxGP
U301: STM32H7B0VBTx; LQFP-100_14x14mm_P0.5mm
X301: 8MHz; Crystal_SMD_2520-4Pin_2.5x2.0mm

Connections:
3.3V_MAIN: C305.1, C307.2, C308.1, C309.2, C310.1, C311.2, C312.1, C313.2, C314.1, J301.1 (VTref), R301.1, R307.1, R308.1, U301.6 (VBAT), U301.11 (VDD), U301.20 (VREF+), U301.21 (VDDA), U301.27 (VDD), U301.50 (VDD), U301.75 (VDD), U301.100 (VDD); also elsewhere on the board
/BUS_SCL: R307.2, U301.59 (I2C4_SCL); also elsewhere on the board
/BUS_SDA: R308.2, U301.60 (I2C4_SDA); also elsewhere on the board
/BUS_UART_RX: U301.61 (UART9_RX); also elsewhere on the board
/BUS_UART_TX: U301.62 (UART9_TX); also elsewhere on the board
/DRDY_INT_B: U301.36 (PB2); also elsewhere on the board
/DRDY_M: U301.37 (PE7); also elsewhere on the board
/INT_A/G: U301.38 (PE8); also elsewhere on the board
/MCU/BOOT: SW301.1, U301.94 (BOOT0)
/MCU/FDCAN1_RX: U301.81 (FDCAN1_RX); also elsewhere on the board
/MCU/FDCAN1_TX: U301.82 (FDCAN1_TX); also elsewhere on the board
/MCU/I2C3_SCL: U301.67 (I2C3_SCL); also elsewhere on the board
/MCU/I2C3_SDA: U301.66 (I2C3_SDA); also elsewhere on the board
/MCU/NRST: C302.1, J301.10 (~RESET), R301.2, SW302.1, U301.14 (NRST); also elsewhere on the board
/MCU/OSC32_IN: U301.8 (RCC_OSC32_IN); also elsewhere on the board
/MCU/OSC_IN: C304.2, U301.12 (PH0), X301.3
/MCU/OSC_OUT: C306.2, U301.13 (PH1), X301.1
/MCU/PA0: U301.22 (PA0); also elsewhere on the board
/MCU/PA1: R302.1, U301.23 (PA1)
/MCU/PA2: R303.1, U301.24 (PA2)
/MCU/PA3: R304.1, U301.25 (PA3)
/MCU/PA15: U301.77 (PA15); also elsewhere on the board
/MCU/PB4: U301.90 (PB4); also elsewhere on the board
/MCU/PB5: U301.91 (PB5); also elsewhere on the board
/MCU/PB10: U301.46 (PB10); also elsewhere on the board
/MCU/PC4: U301.32 (PC4); also elsewhere on the board
/MCU/PC5: U301.33 (PC5); also elsewhere on the board
/MCU/PC6: U301.63 (PC6); also elsewhere on the board
/MCU/PD2: U301.83 (PD2); also elsewhere on the board
/MCU/PE15: U301.45 (PE15); also elsewhere on the board
/MCU/SDWIO: J301.2 (SWDIO/TMS), U301.72 (DEBUG_JTMS-SWDIO)
/MCU/SPI1_MISO: U301.30 (SPI1_MISO); also elsewhere on the board
/MCU/SPI1_MOSI: U301.31 (SPI1_MOSI); also elsewhere on the board
/MCU/SPI1_NSS: U301.28 (SPI1_NSS); also elsewhere on the board
/MCU/SPI1_SCK: U301.29 (SPI1_SCK); also elsewhere on the board
/MCU/SPI4_MISO: U301.43 (SPI4_MISO); also elsewhere on the board
/MCU/SPI4_MOSI: U301.44 (SPI4_MOSI); also elsewhere on the board
/MCU/SPI4_NSS: U301.41 (SPI4_NSS); also elsewhere on the board
/MCU/SPI4_SCK: U301.42 (SPI4_SCK); also elsewhere on the board
/MCU/SWCLK: J301.4 (SWCLK/TCK), U301.76 (DEBUG_JTCK-SWCLK)
/MCU/SWO: J301.6 (SWO/TDO), U301.89 (DEBUG_JTDO-SWO)
/MCU/USART2_DE: U301.85 (USART2_DE); also elsewhere on the board
/MCU/USART2_RX: U301.87 (USART2_RX); also elsewhere on the board
/MCU/USART2_TX: U301.86 (USART2_TX); also elsewhere on the board
/MCU/USB_OTG_HS_N: J302.A7 (D-), J302.B7 (D-), U301.70 (USB_OTG_HS_DM)
/MCU/USB_OTG_HS_P: J302.A6 (D+), J302.B6 (D+), U301.71 (USB_OTG_HS_DP)
/MCU/VCAP: C301.1, U301.48 (VCAP)
/MCU/VCAP1: C303.1, U301.73 (VCAP)
/SPI_CS: U301.51 (SPI2_NSS); also elsewhere on the board
/SPI_CS1: U301.55 (PD8); also elsewhere on the board
/SPI_CS2: U301.56 (PD9); also elsewhere on the board
/SPI_MISO: U301.53 (SPI2_MISO); also elsewhere on the board
/SPI_MOSI: U301.54 (SPI2_MOSI); also elsewhere on the board
/SPI_SCK: U301.52 (SPI2_SCK); also elsewhere on the board
/_SCL: U301.92 (I2C1_SCL); also elsewhere on the board
/_SDA: U301.93 (I2C1_SDA); also elsewhere on the board
/bat_alert: U301.1 (PE2); also elsewhere on the board
GND: C301.2, C302.2, C303.2, C304.1, C305.2, C306.1, C307.1, C308.2, C309.1, C310.2, C311.1, C312.2, C313.1, C314.2, D301.1 (K), D302.1 (K), D303.1 (K), H301.1 (1_1), H302.1 (1_1), H303.1 (1_1), H304.1 (1_1), J301.3 (GND), J301.5 (GND), J301.9 (GNDDetect), J302.A1 (GND), J302.A12 (GND), J302.B1 (GND), J302.B12 (GND), J302.SH (SHIELD), R309.2, R310.2, SW301.2, SW301.SH (B), SW302.2, SW302.SH (B), U301.10 (VSS), U301.19 (VSSA), U301.26 (VSS), U301.49 (VSS), U301.74 (VSS), U301.99 (VSS), X301.2, X301.4; also elsewhere on the board
unnamed: D301.2 (A), R302.2
unnamed: D302.2 (A), R303.2
unnamed: D303.2 (A), R304.2
unnamed: J302.A5 (CC1), R309.1
unnamed: J302.B5 (CC2), R310.1
VBUS: J302.A4 (VBUS), J302.A9 (VBUS), J302.B4 (VBUS), J302.B9 (VBUS); also elsewhere on the board

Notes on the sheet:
MCU
USB CONN
EXTRAs
DECOUPLAGES
SW CONN
OSCILLATOR
BOOT & RESET

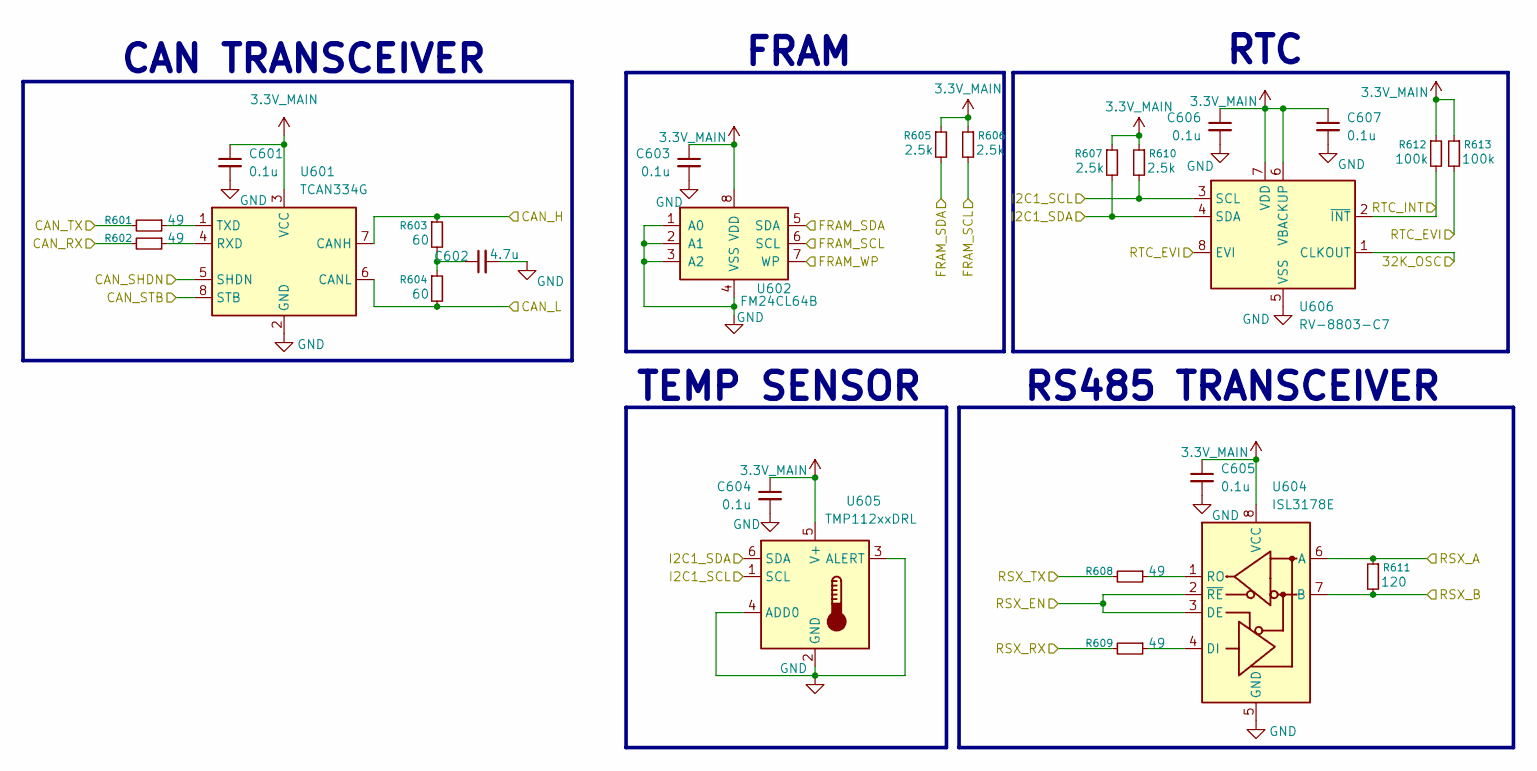
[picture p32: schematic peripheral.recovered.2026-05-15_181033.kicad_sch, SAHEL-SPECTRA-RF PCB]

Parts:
C601, C603, C604, C605, C606, C607: 0.1u; C_0402_1005Metric
C602: 4.7u; C_0402_1005Metric
R601, R602, R608, R609: 49; R_0402_1005Metric
R603, R604: 60; R_0402_1005Metric
R605, R606, R607, R610: 2.5k; R_0402_1005Metric
R611: 120; R_0402_1005Metric
R612, R613: 100k; R_0402_1005Metric
U601: TCAN334G; TSOT-23-8
U602: FM24CL64B; SOIC-8_3.9x4.9mm_P1.27mm
U604: ISL3178E; SOIC-8_3.9x4.9mm_P1.27mm
U605: TMP112xxDRL; SOT-563
U606: RV-8803-C7; MicroCrystal_C7_SON-8_1.5x3.2mm_P0.9mm

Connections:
3.3V_MAIN: C601.1, C603.1, C604.1, C605.1, C606.1, C607.1, R605.1, R606.1, R607.1, R610.1, R612.1, R613.1, U601.3 (VCC), U602.8 (VDD), U604.8 (VCC), U605.5 (V+), U606.6 (VBACKUP), U606.7 (VDD); also elsewhere on the board
/BUS_RS_A: R611.1, U604.6 (A); also elsewhere on the board
/BUS_RS_B: R611.2, U604.7 (B); also elsewhere on the board
/CAN_H: R603.1, U601.7 (CANH); also elsewhere on the board
/CAN_L: R604.2, U601.6 (CANL); also elsewhere on the board
/MCU/FDCAN1_RX: R602.2; also elsewhere on the board
/MCU/FDCAN1_TX: R601.2; also elsewhere on the board
/MCU/I2C3_SCL: R606.2, U602.6 (SCL); also elsewhere on the board
/MCU/I2C3_SDA: R605.2, U602.5 (SDA); also elsewhere on the board
/MCU/OSC32_IN: U606.1 (CLKOUT); also elsewhere on the board
/MCU/PA15: U601.5 (SHDN); also elsewhere on the board
/MCU/PB4: R613.2, U606.8 (EVI); also elsewhere on the board
/MCU/PB5: R612.2, U606.2 (~INT); also elsewhere on the board
/MCU/PC6: U602.7 (WP); also elsewhere on the board
/MCU/PD2: U601.8 (STB); also elsewhere on the board
/MCU/USART2_DE: U604.2 (~RE), U604.3 (DE); also elsewhere on the board
/MCU/USART2_RX: R609.2; also elsewhere on the board
/MCU/USART2_TX: R608.2; also elsewhere on the board
/_SCL: R610.2, U605.1 (SCL), U606.3 (SCL); also elsewhere on the board
/_SDA: R607.2, U605.6 (SDA), U606.4 (SDA); also elsewhere on the board
GND: C601.2, C602.2, C603.2, C604.2, C605.2, C606.2, C607.2, U601.2 (GND), U602.1 (A0), U602.2 (A1), U602.3 (A2), U602.4 (VSS), U604.5 (GND), U605.2 (GND), U605.3 (ALERT), U605.4 (ADD0), U606.5 (VSS); also elsewhere on the board
unnamed: C602.1, R603.2, R604.1
unnamed: R602.1, U601.4 (RXD)
unnamed: R601.1, U601.1 (TXD)
unnamed: R609.1, U604.4 (DI)
unnamed: R608.1, U604.1 (RO)

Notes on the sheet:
RTC
CAN TRANSCEIVER
RS485 TRANSCEIVER
TEMP SENSOR
FRAM

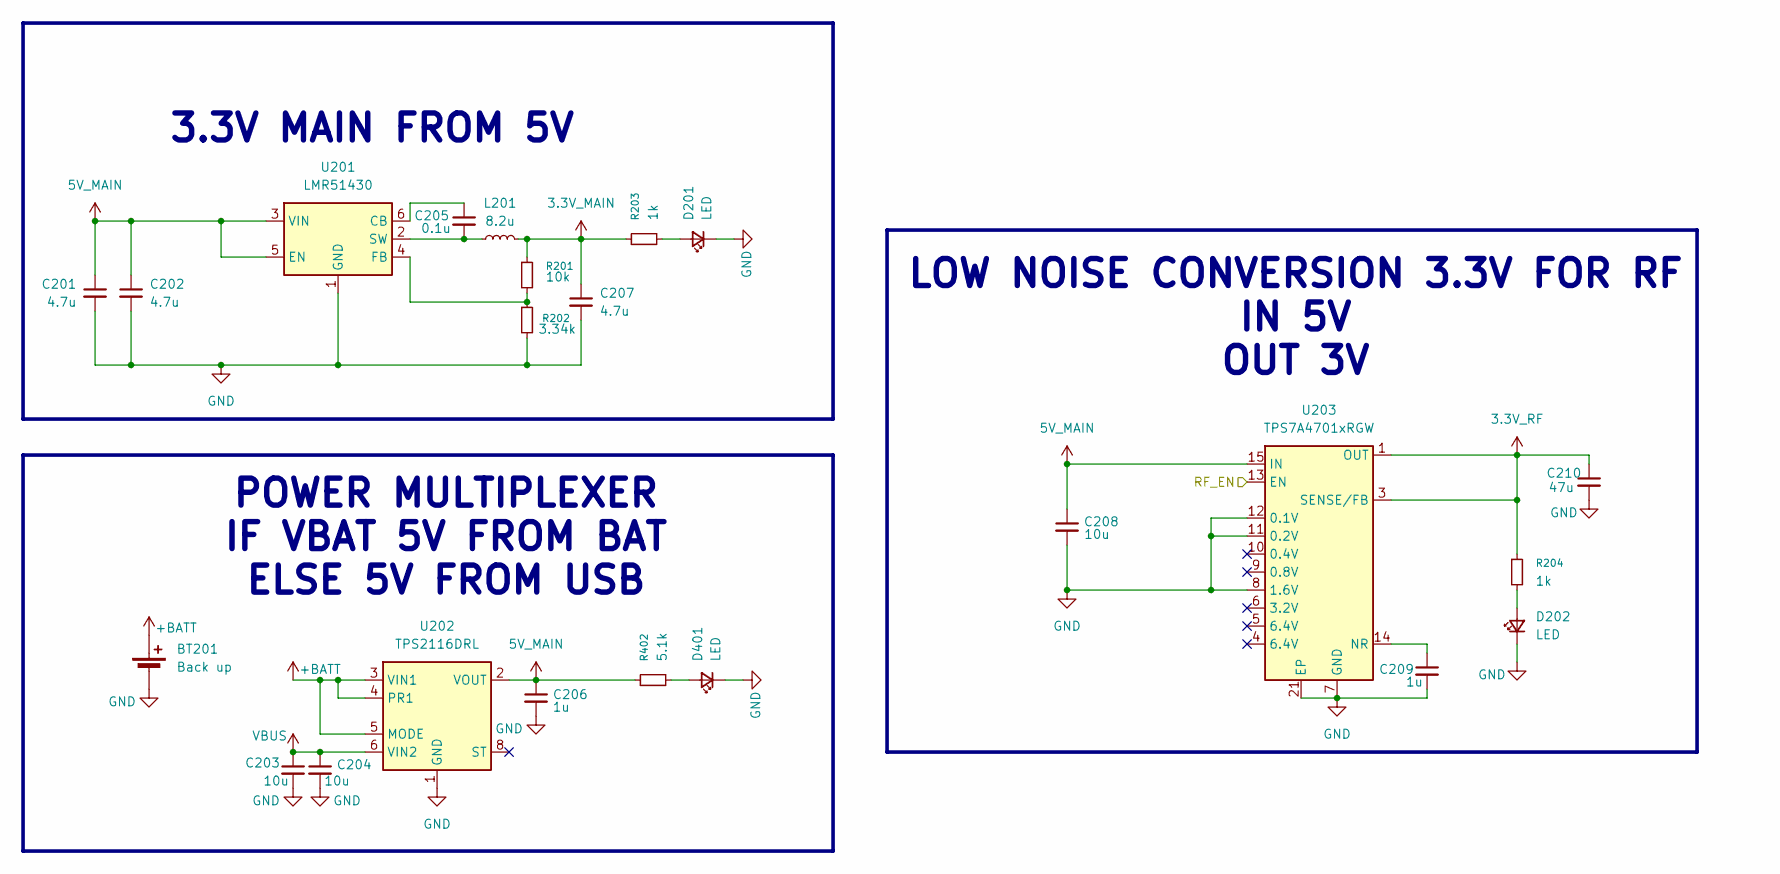
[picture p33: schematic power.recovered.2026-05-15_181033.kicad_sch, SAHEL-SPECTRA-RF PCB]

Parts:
BT201: Back up; JST_XH_S2B-XH-A_1x02_P2.50mm_Horizontal
C201, C202, C207: 4.7u; C_0603_1608Metric
C203, C204, C208: 10u; C_0402_1005Metric
C205: 0.1u; C_0402_1005Metric
C206, C209: 1u; C_0402_1005Metric
C210: 47u; C_0402_1005Metric
D201, D202, D401: LED; LED_0402_1005Metric
L201: 8.2u; L_Wurth_WE-LQSH-2010
R201: 10k; R_0402_1005Metric
R202: 3.34k; R_0402_1005Metric
R203, R204: 1k; R_0402_1005Metric
R402: 5.1k; R_0402_1005Metric
U201: LMR51430; SOT-23-6
U202: TPS2116DRL; SOT-583-8
U203: TPS7A4701xRGW; Texas_RGW0020A_VQFN-20-1EP_5x5mm_P0.65mm_EP3.15x3.15mm_Ther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

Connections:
3.3V_MAIN: C207.1, L201.2, R201.1, R203.1; also elsewhere on the board
3.3V_RF: C210.1, R204.1, U203.1 (OUT), U203.3 (SENSE/FB), U203.20 (OUT); also elsewhere on the board
5V_MAIN: C201.1, C202.1, C206.1, C208.1, R402.1, U201.3 (VIN), U201.5 (EN), U202.2 (VOUT), U202.7 (VOUT), U203.15 (IN), U203.16 (IN)
+BATT: BT201.1 (+), U202.3 (VIN1), U202.4 (PR1), U202.5 (MODE)
/MCU/PA0: U203.13 (EN); also elsewhere on the board
GND: BT201.2 (-), C201.2, C202.2, C203.2, C204.2, C206.2, C207.2, C208.2, C209.2, C210.2, D201.1 (K), D202.1 (K), D401.1 (K), R202.2, U201.1 (GND), U202.1 (GND), U203.7 (GND), U203.8 (1.6V), U203.11 (0.2V), U203.12 (0.1V), U203.21 (EP); also elsewhere on the board
unnamed: D201.2 (A), R203.2
unnamed: D202.2 (A), R204.2
unnamed: D401.2 (A), R402.2
unnamed: C205.1, U201.6 (CB)
unnamed: R201.2, R202.1, U201.4 (FB)
unnamed: C205.2, L201.1, U201.2 (SW)
unnamed: C209.1, U203.14 (NR)
VBUS: C203.1, C204.1, U202.6 (VIN2); also elsewhere on the board

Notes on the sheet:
POWER MULTIPLEXER IF VBAT 5V FROM BAT ELSE 5V FROM USB
LOW NOISE CONVERSION 3.3V FOR RF IN 5V OUT 3V
3.3V MAIN FROM 5V

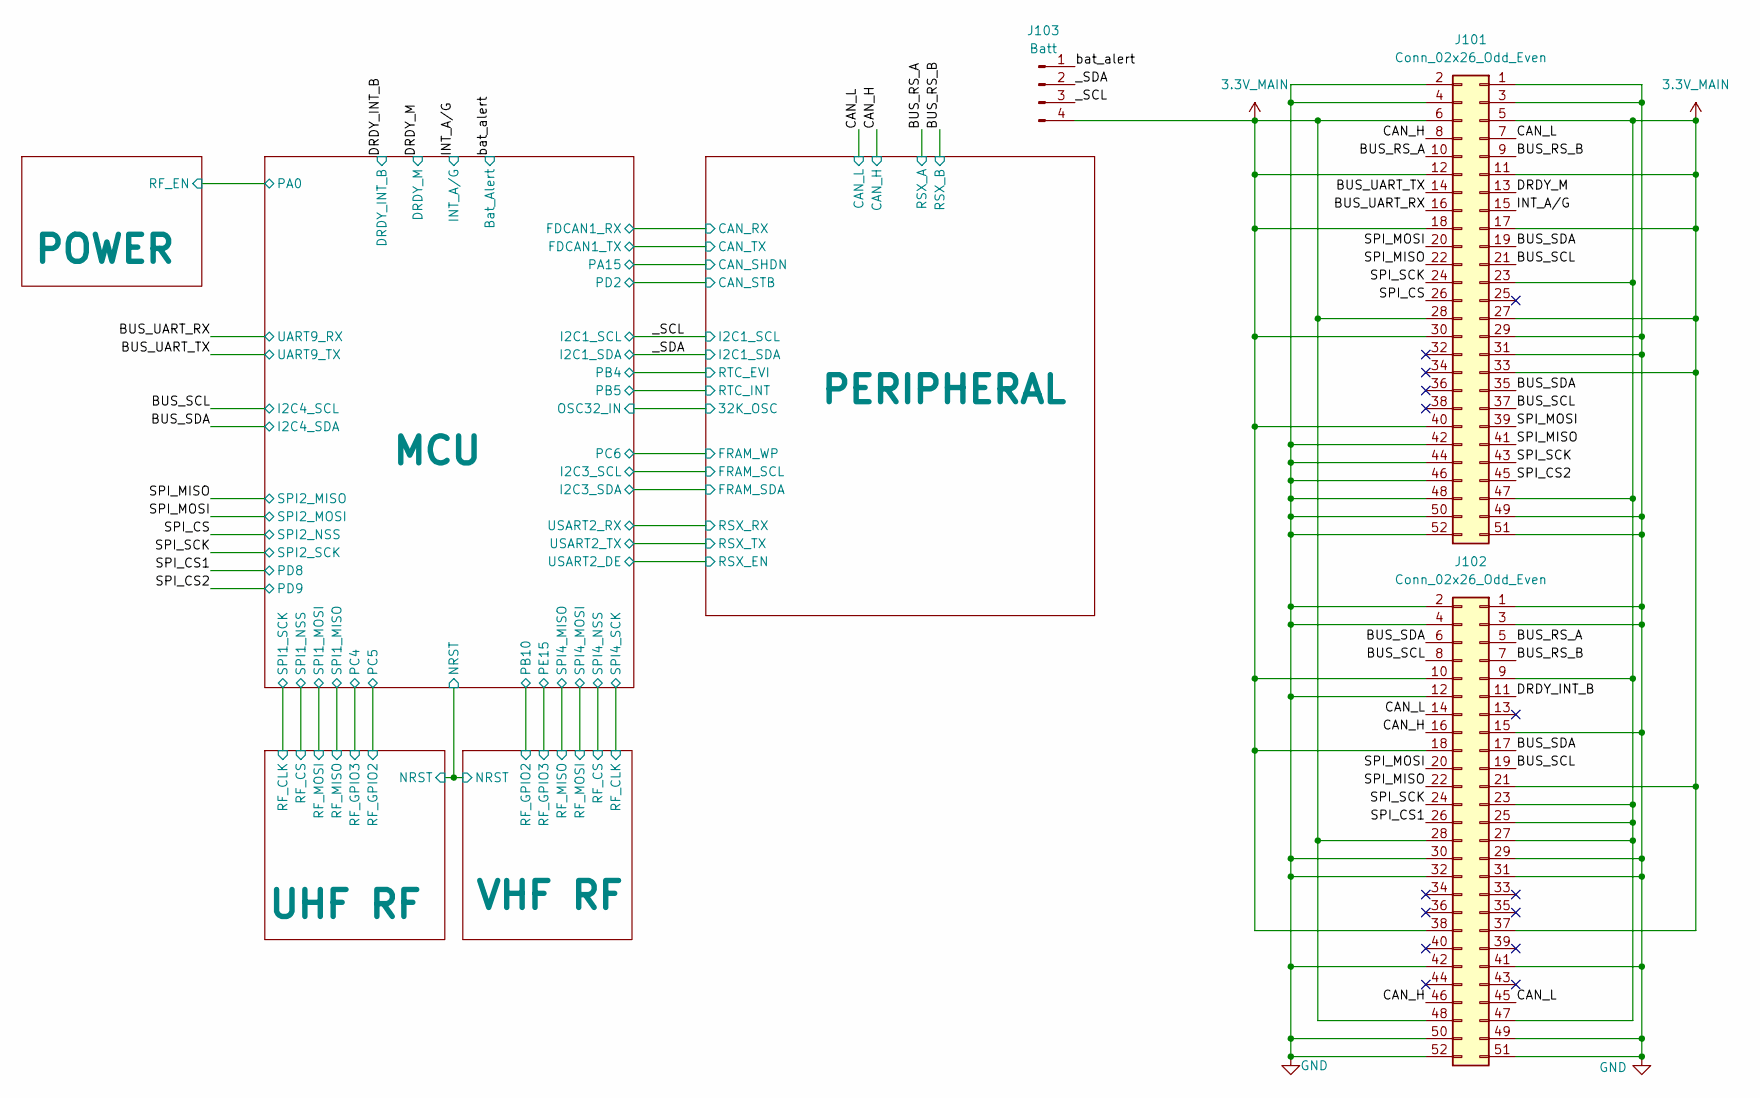
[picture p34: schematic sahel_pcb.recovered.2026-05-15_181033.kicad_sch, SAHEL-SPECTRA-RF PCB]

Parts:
J101, J102: Conn_02x26_Odd_Even; PinSocket_2x26_P2.54mm_Vertical
J103: Batt; JST_ZH_B4B-ZR_1x04_P1.50mm_Vertical

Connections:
3.3V_MAIN: J101.5, J101.6, J101.11, J101.12, J101.17, J101.18, J101.23, J101.27, J101.28, J101.30, J101.33, J101.40, J101.47, J102.9, J102.10, J102.18, J102.21, J102.23, J102.25, J102.27, J102.28, J102.37, J102.38, J102.47, J102.48, J103.4; also elsewhere on the board
/BUS_RS_A: J101.10, J102.5; also elsewhere on the board
/BUS_RS_B: J101.9, J102.7; also elsewhere on the board
/BUS_SCL: J101.21, J101.37, J102.8, J102.19; also elsewhere on the board
/BUS_SDA: J101.19, J101.35, J102.6, J102.17; also elsewhere on the board
/BUS_UART_RX: J101.16; also elsewhere on the board
/BUS_UART_TX: J101.14; also elsewhere on the board
/CAN_H: J101.8, J102.16, J102.46; also elsewhere on the board
/CAN_L: J101.7, J102.14, J102.45; also elsewhere on the board
/DRDY_INT_B: J102.11; also elsewhere on the board
/DRDY_M: J101.13; also elsewhere on the board
/INT_A/G: J101.15; also elsewhere on the board
/SPI_CS: J101.26; also elsewhere on the board
/SPI_CS1: J102.26; also elsewhere on the board
/SPI_CS2: J101.45; also elsewhere on the board
/SPI_MISO: J101.22, J101.41, J102.22; also elsewhere on the board
/SPI_MOSI: J101.20, J101.39, J102.20; also elsewhere on the board
/SPI_SCK: J101.24, J101.43, J102.24; also elsewhere on the board
/_SCL: J103.3; also elsewhere on the board
/_SDA: J103.2; also elsewhere on the board
/bat_alert: J103.1; also elsewhere on the board
GND: J101.1, J101.2, J101.3, J101.4, J101.29, J101.31, J101.42, J101.44, J101.46, J101.48, J101.49, J101.50, J101.51, J101.52, J102.1, J102.2, J102.3, J102.4, J102.12, J102.15, J102.29, J102.30, J102.31, J102.32, J102.41, J102.42, J102.49, J102.50, J102.51, J102.52; also elsewhere on the board

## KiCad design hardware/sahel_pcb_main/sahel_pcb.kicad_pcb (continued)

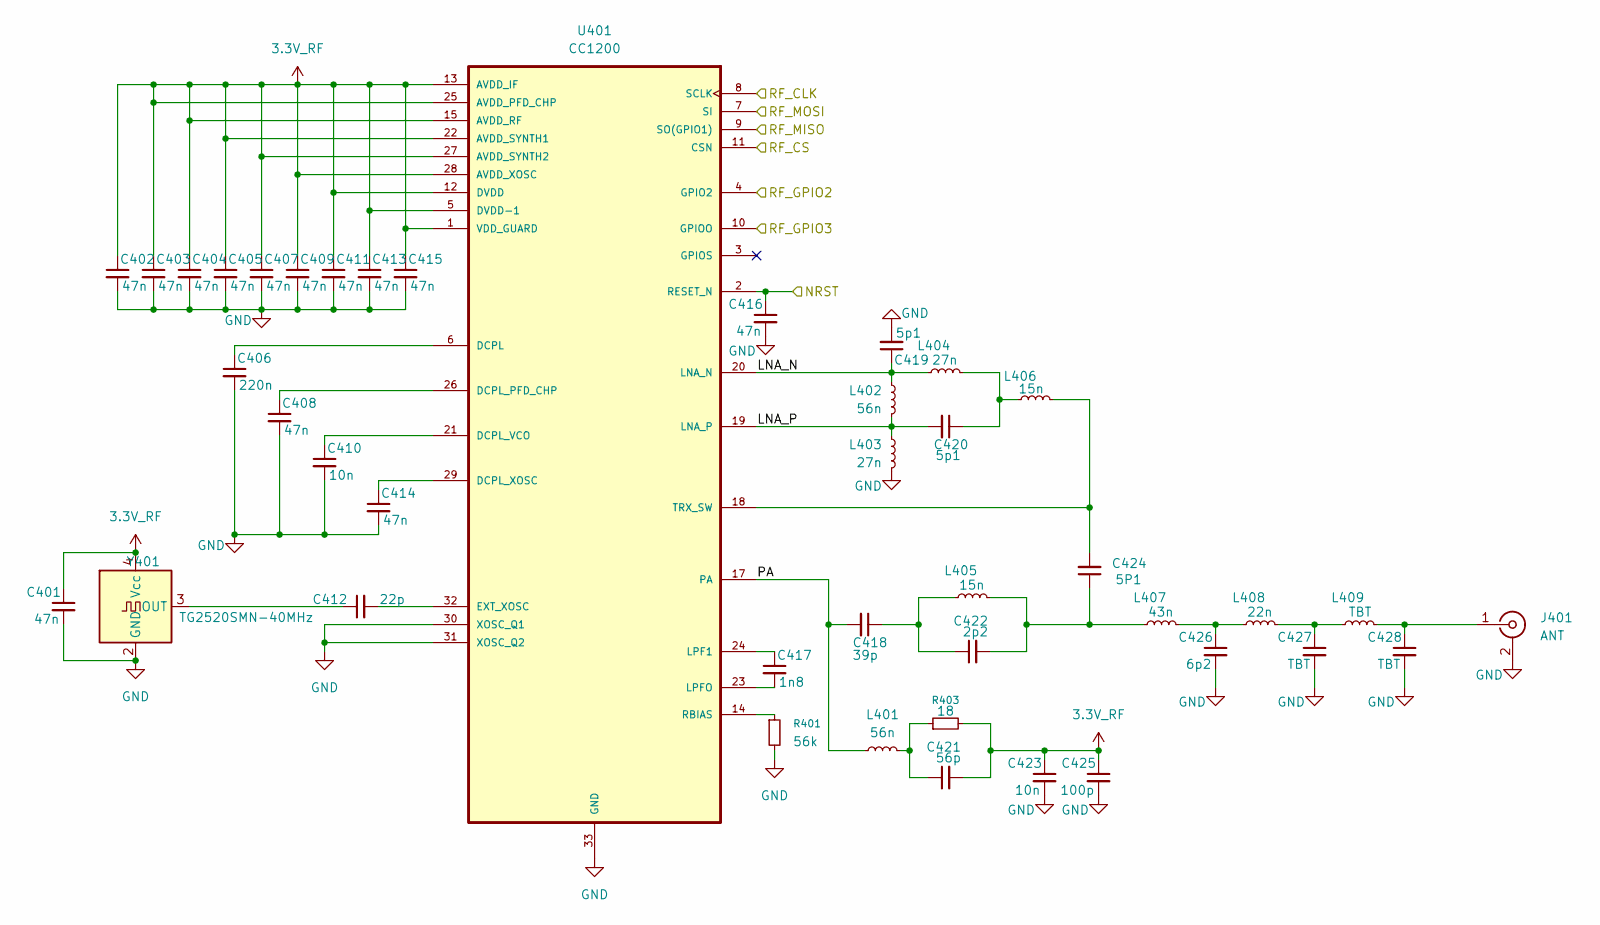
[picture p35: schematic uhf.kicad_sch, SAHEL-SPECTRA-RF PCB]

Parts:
C401, C402, C403, C404, C405, C407, C408, C409, C411, C413, C414, C415, C416: 47n; C_0402_1005Metric
C406: 220n; C_0402_1005Metric
C410, C423: 10n; C_0402_1005Metric
C412: 22p; C_0402_1005Metric
C417: 1n8; C_0402_1005Metric
C418: 39p; C_0402_1005Metric
C419, C420: 5p1; C_0402_1005Metric
C421: 56p; C_0402_1005Metric
C422: 2p2; C_0402_1005Metric
C424: 5P1; C_0402_1005Metric
C425: 100p; C_0402_1005Metric
C426: 6p2; C_0402_1005Metric
C427, C428: TBT; C_0402_1005Metric
J401: ANT; U.FL_Hirose_U.FL-R-SMT-1_Vertical
L401, L402: 56n; L_0402_1005Metric
L403, L404: 27n; L_0402_1005Metric
L405, L406: 15n; L_0402_1005Metric
L407: 43n; L_0402_1005Metric
L408: 22n; L_0402_1005Metric
L409: TBT; L_0402_1005Metric
R401: 56k; R_0402_1005Metric
R403: 18; R_0402_1005Metric
U401: CC1200; QFN-32-1EP_5x5mm_P0.5mm_EP3.45x3.45mm
Y401: TG2520SMN-40MHz; Crystal_SMD_WE_CFPX-218-4Pin_2.5x2.0mm

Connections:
3.3V_RF: C401.1, C402.1, C403.1, C404.1, C405.1, C407.1, C409.1, C411.1, C413.1, C415.1, C421.2, C423.1, C425.1, R403.2, U401.1 (VDD_GUARD), U401.5 (DVDD-1), U401.12 (DVDD), U401.13 (AVDD_IF), U401.15 (AVDD_RF), U401.22 (AVDD_SYNTH1), U401.25 (AVDD_PFD_CHP), U401.27 (AVDD_SYNTH2), U401.28 (AVDD_XOSC), Y401.4 (Vcc); also elsewhere on the board
/MCU/NRST: C416.1, U401.2 (RESET_N); also elsewhere on the board
/MCU/PC4: U401.10 (GPIOO); also elsewhere on the board
/MCU/PC5: U401.4 (GPIO2); also elsewhere on the board
/MCU/SPI1_MISO: U401.9 (SO(GPIO1)); also elsewhere on the board
/MCU/SPI1_MOSI: U401.7 (SI); also elsewhere on the board
/MCU/SPI1_NSS: U401.11 (CSN); also elsewhere on the board
/MCU/SPI1_SCK: U401.8 (SCLK); also elsewhere on the board
/UHF RF/LNA_N: C419.1, L402.2, L404.2, U401.20 (LNA_N)
/UHF RF/LNA_P: C420.2, L402.1, L403.2, U401.19 (LNA_P)
/UHF RF/PA: C418.2, L401.1, U401.17 (PA)
GND: C401.2, C402.2, C403.2, C404.2, C405.2, C406.2, C407.2, C408.2, C409.2, C410.2, C411.2, C413.2, C414.2, C415.2, C416.2, C419.2, C423.2, C425.2, C426.2, C427.2, C428.2, J401.2 (Ext), L403.1, R401.2, U401.30 (XOSC_Q1), U401.31 (XOSC_Q2), U401.33 (GND), Y401.2 (GND); also elsewhere on the board
unnamed: C418.1, C422.1, L405.2
unnamed: C420.1, L404.1, L406.2
unnamed: C421.1, L401.2, R403.1
unnamed: C422.2, C424.1, L405.1, L407.2
unnamed: C426.1, L407.1, L408.2
unnamed: C427.1, L408.1, L409.2
unnamed: C428.1, J401.1 (In), L409.1
unnamed: C406.1, U401.6 (DCPL)
unnamed: C408.1, U401.26 (DCPL_PFD_CHP)
unnamed: C410.1, U401.21 (DCPL_VCO)
unnamed: C414.1, U401.29 (DCPL_XOSC)
unnamed: C412.2, U401.32 (EXT_XOSC)
unnamed: C417.1, U401.24 (LPF1)
unnamed: C417.2, U401.23 (LPFO)
unnamed: R401.1, U401.14 (RBIAS)
unnamed: C424.2, L406.1, U401.18 (TRX_SW)
unnamed: C412.1, Y401.3 (OUT)

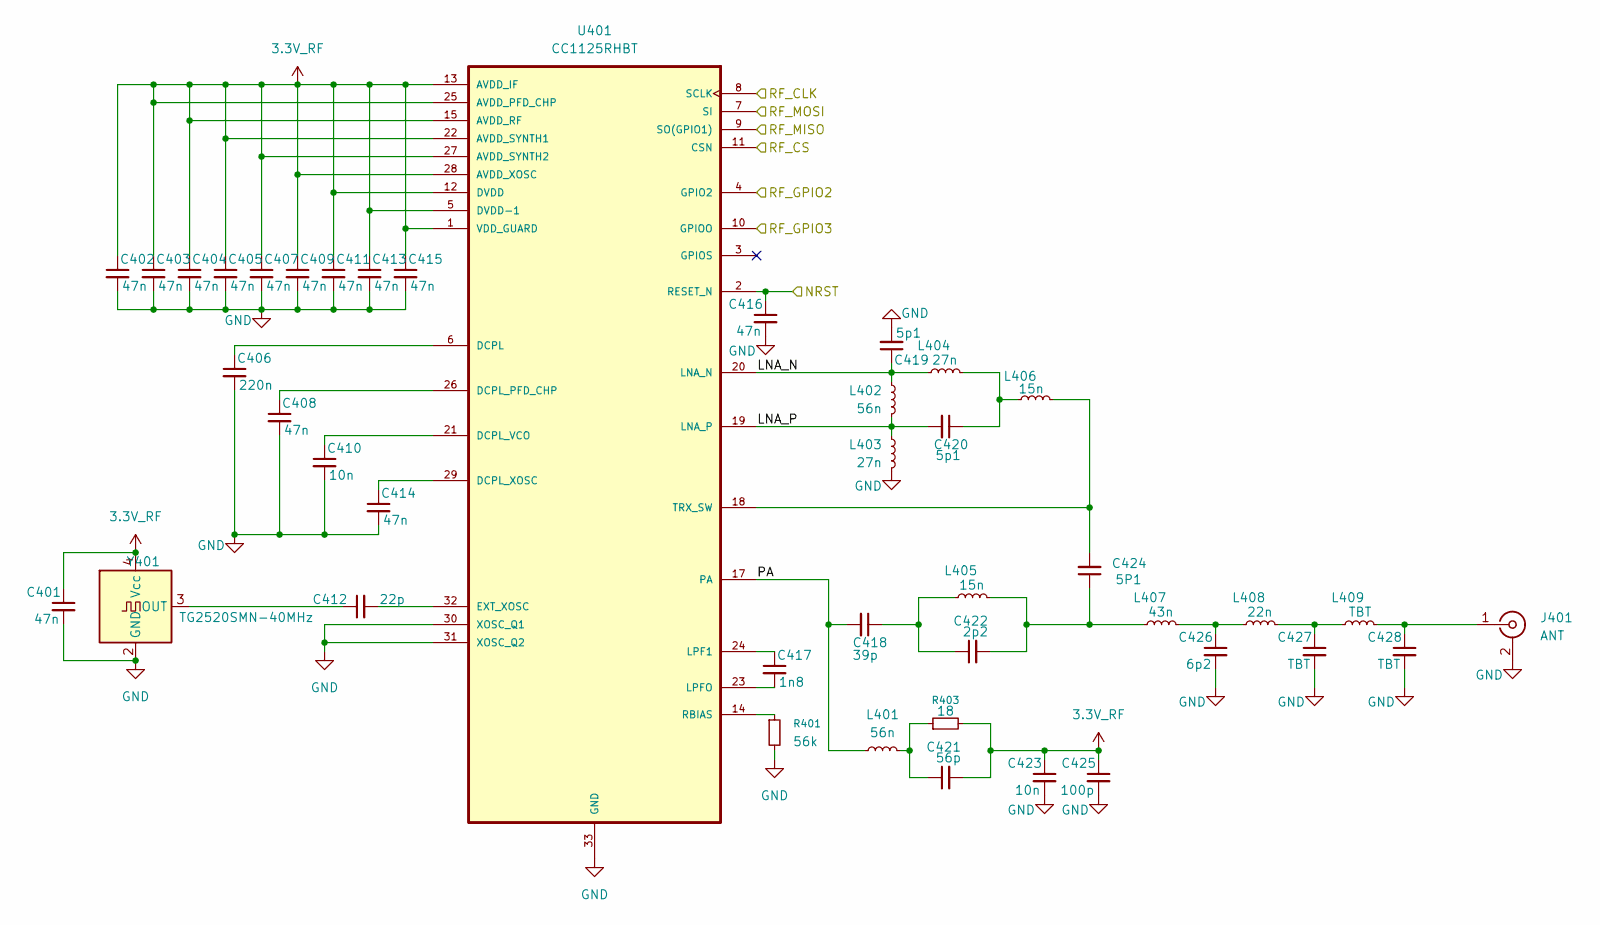
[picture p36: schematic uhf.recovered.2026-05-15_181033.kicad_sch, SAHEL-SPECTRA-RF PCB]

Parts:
C401, C402, C403, C404, C405, C407, C408, C409, C411, C413, C414, C415, C416: 47n; C_0402_1005Metric
C406: 220n; C_0402_1005Metric
C410, C423: 10n; C_0402_1005Metric
C412: 22p; C_0402_1005Metric
C417: 1n8; C_0402_1005Metric
C418: 39p; C_0402_1005Metric
C419, C420: 5p1; C_0402_1005Metric
C421: 56p; C_0402_1005Metric
C422: 2p2; C_0402_1005Metric
C424: 5P1; C_0402_1005Metric
C425: 100p; C_0402_1005Metric
C426: 6p2; C_0402_1005Metric
C427, C428: TBT; C_0402_1005Metric
J401: ANT; U.FL_Hirose_U.FL-R-SMT-1_Vertical
L401, L402: 56n; L_0402_1005Metric
L403, L404: 27n; L_0402_1005Metric
L405, L406: 15n; L_0402_1005Metric
L407: 43n; L_0402_1005Metric
L408: 22n; L_0402_1005Metric
L409: TBT; L_0402_1005Metric
R401: 56k; R_0402_1005Metric
R403: 18; R_0402_1005Metric
U401: CC1125RHBT; QFN-32-1EP_5x5mm_P0.5mm_EP3.45x3.45mm
Y401: TG2520SMN-40MHz; Crystal_SMD_WE_CFPX-218-4Pin_2.5x2.0mm

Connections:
3.3V_RF: C401.1, C402.1, C403.1, C404.1, C405.1, C407.1, C409.1, C411.1, C413.1, C415.1, C421.2, C423.1, C425.1, R403.2, U401.1 (VDD_GUARD), U401.5 (DVDD-1), U401.12 (DVDD), U401.13 (AVDD_IF), U401.15 (AVDD_RF), U401.22 (AVDD_SYNTH1), U401.25 (AVDD_PFD_CHP), U401.27 (AVDD_SYNTH2), U401.28 (AVDD_XOSC), Y401.4 (Vcc); also elsewhere on the board
/MCU/NRST: C416.1, U401.2 (RESET_N); also elsewhere on the board
/MCU/PC4: U401.10 (GPIOO); also elsewhere on the board
/MCU/PC5: U401.4 (GPIO2); also elsewhere on the board
/MCU/SPI1_MISO: U401.9 (SO(GPIO1)); also elsewhere on the board
/MCU/SPI1_MOSI: U401.7 (SI); also elsewhere on the board
/MCU/SPI1_NSS: U401.11 (CSN); also elsewhere on the board
/MCU/SPI1_SCK: U401.8 (SCLK); also elsewhere on the board
/UHF RF/LNA_N: C419.1, L402.2, L404.2, U401.20 (LNA_N)
/UHF RF/LNA_P: C420.2, L402.1, L403.2, U401.19 (LNA_P)
/UHF RF/PA: C418.2, L401.1, U401.17 (PA)
GND: C401.2, C402.2, C403.2, C404.2, C405.2, C406.2, C407.2, C408.2, C409.2, C410.2, C411.2, C413.2, C414.2, C415.2, C416.2, C419.2, C423.2, C425.2, C426.2, C427.2, C428.2, J401.2 (Ext), L403.1, R401.2, U401.30 (XOSC_Q1), U401.31 (XOSC_Q2), U401.33 (GND), Y401.2 (GND); also elsewhere on the board
unnamed: C418.1, C422.1, L405.2
unnamed: C420.1, L404.1, L406.2
unnamed: C421.1, L401.2, R403.1
unnamed: C422.2, C424.1, L405.1, L407.2
unnamed: C426.1, L407.1, L408.2
unnamed: C427.1, L408.1, L409.2
unnamed: C428.1, J401.1 (In), L409.1
unnamed: C406.1, U401.6 (DCPL)
unnamed: C408.1, U401.26 (DCPL_PFD_CHP)
unnamed: C410.1, U401.21 (DCPL_VCO)
unnamed: C414.1, U401.29 (DCPL_XOSC)
unnamed: C412.2, U401.32 (EXT_XOSC)
unnamed: C417.1, U401.24 (LPF1)
unnamed: C417.2, U401.23 (LPFO)
unnamed: R401.1, U401.14 (RBIAS)
unnamed: C424.2, L406.1, U401.18 (TRX_SW)
unnamed: C412.1, Y401.3 (OUT)

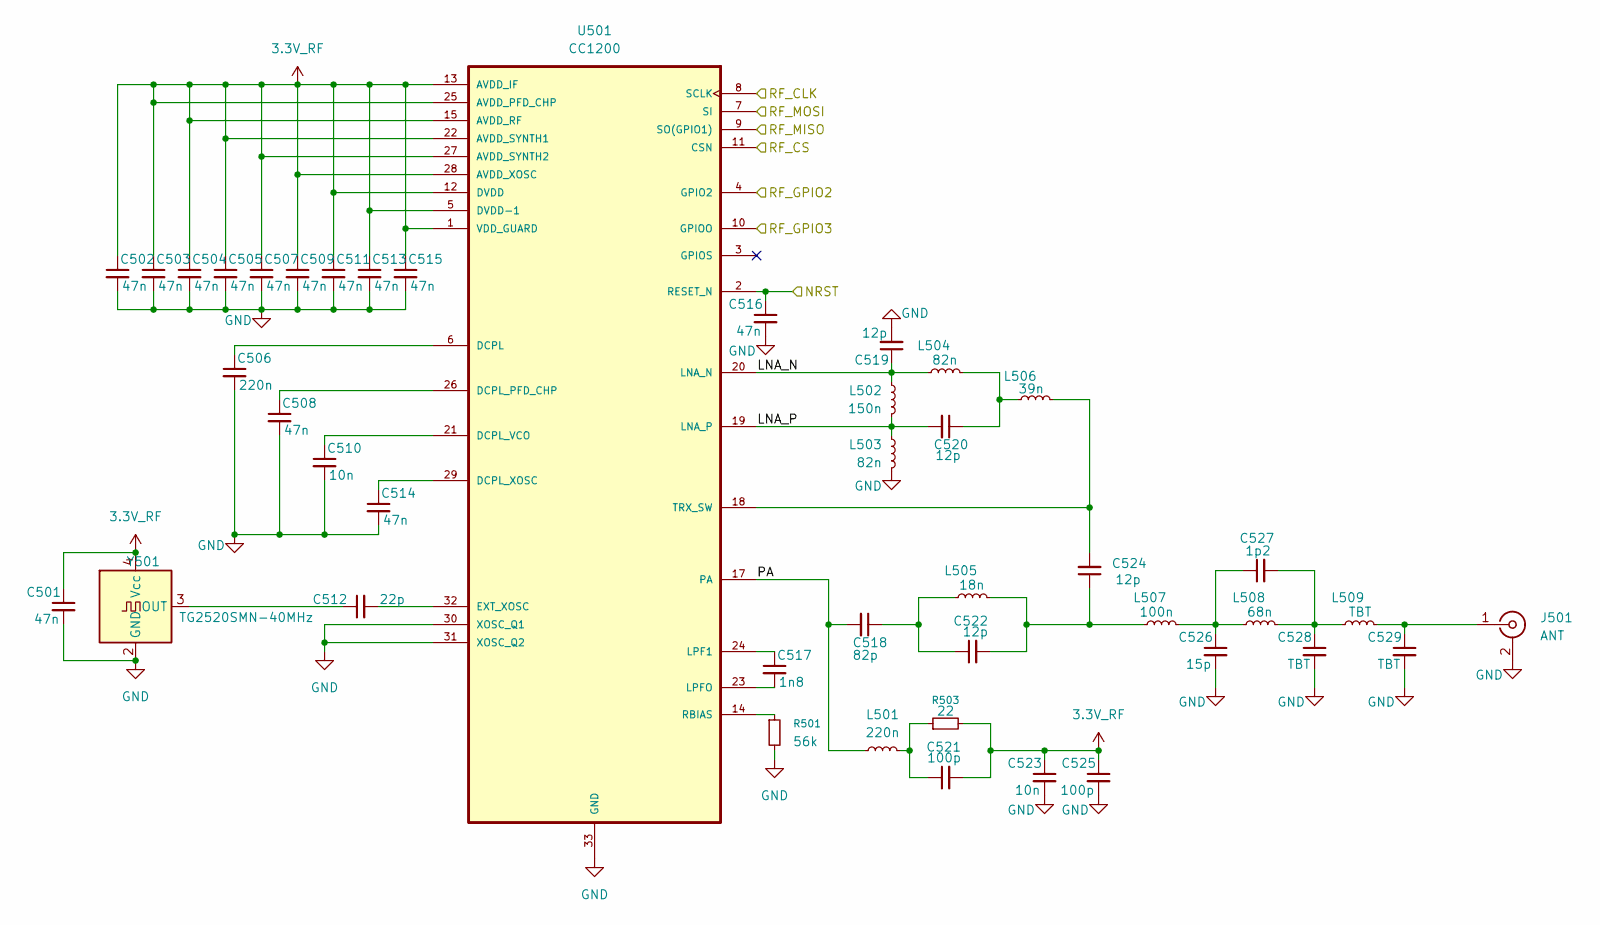
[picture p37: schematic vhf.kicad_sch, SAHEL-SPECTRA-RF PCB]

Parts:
C501, C502, C503, C504, C505, C507, C508, C509, C511, C513, C514, C515, C516: 47n; C_0402_1005Metric
C506: 220n; C_0402_1005Metric
C510, C523: 10n; C_0402_1005Metric
C512: 22p; C_0402_1005Metric
C517: 1n8; C_0402_1005Metric
C518: 82p; C_0402_1005Metric
C519, C520, C522, C524: 12p; C_0402_1005Metric
C521, C525: 100p; C_0402_1005Metric
C526: 15p; C_0402_1005Metric
C527: 1p2; C_0402_1005Metric
C528, C529: TBT; C_0402_1005Metric
J501: ANT; U.FL_Hirose_U.FL-R-SMT-1_Vertical
L501: 220n; L_0402_1005Metric
L502: 150n; L_0402_1005Metric
L503, L504: 82n; L_0402_1005Metric
L505: 18n; L_0402_1005Metric
L506: 39n; L_0402_1005Metric
L507: 100n; L_0402_1005Metric
L508: 68n; L_0402_1005Metric
L509: TBT; L_0402_1005Metric
R501: 56k; R_0402_1005Metric
R503: 22; R_0402_1005Metric
U501: CC1200; QFN-32-1EP_5x5mm_P0.5mm_EP3.45x3.45mm
Y501: TG2520SMN-40MHz; Crystal_SMD_WE_CFPX-218-4Pin_2.5x2.0mm

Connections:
3.3V_RF: C501.1, C502.1, C503.1, C504.1, C505.1, C507.1, C509.1, C511.1, C513.1, C515.1, C521.2, C523.1, C525.1, R503.2, U501.1 (VDD_GUARD), U501.5 (DVDD-1), U501.12 (DVDD), U501.13 (AVDD_IF), U501.15 (AVDD_RF), U501.22 (AVDD_SYNTH1), U501.25 (AVDD_PFD_CHP), U501.27 (AVDD_SYNTH2), U501.28 (AVDD_XOSC), Y501.4 (Vcc); also elsewhere on the board
/MCU/NRST: C516.1, U501.2 (RESET_N); also elsewhere on the board
/MCU/PB10: U501.4 (GPIO2); also elsewhere on the board
/MCU/PE15: U501.10 (GPIOO); also elsewhere on the board
/MCU/SPI4_MISO: U501.9 (SO(GPIO1)); also elsewhere on the board
/MCU/SPI4_MOSI: U501.7 (SI); also elsewhere on the board
/MCU/SPI4_NSS: U501.11 (CSN); also elsewhere on the board
/MCU/SPI4_SCK: U501.8 (SCLK); also elsewhere on the board
/VHF RF/LNA_N: C519.1, L502.2, L504.2, U501.20 (LNA_N)
/VHF RF/LNA_P: C520.2, L502.1, L503.2, U501.19 (LNA_P)
/VHF RF/PA: C518.2, L501.1, U501.17 (PA)
GND: C501.2, C502.2, C503.2, C504.2, C505.2, C506.2, C507.2, C508.2, C509.2, C510.2, C511.2, C513.2, C514.2, C515.2, C516.2, C519.2, C523.2, C525.2, C526.2, C528.2, C529.2, J501.2 (Ext), L503.1, R501.2, U501.30 (XOSC_Q1), U501.31 (XOSC_Q2), U501.33 (GND), Y501.2 (GND); also elsewhere on the board
unnamed: C518.1, C522.1, L505.2
unnamed: C520.1, L504.1, L506.2
unnamed: C521.1, L501.2, R503.1
unnamed: C522.2, C524.1, L505.1, L507.2
unnamed: C526.1, C527.1, L507.1, L508.2
unnamed: C527.2, C528.1, L508.1, L509.2
unnamed: C529.1, J501.1 (In), L509.1
unnamed: C506.1, U501.6 (DCPL)
unnamed: C508.1, U501.26 (DCPL_PFD_CHP)
unnamed: C510.1, U501.21 (DCPL_VCO)
unnamed: C514.1, U501.29 (DCPL_XOSC)
unnamed: C512.2, U501.32 (EXT_XOSC)
unnamed: C517.1, U501.24 (LPF1)
unnamed: C517.2, U501.23 (LPFO)
unnamed: R501.1, U501.14 (RBIAS)
unnamed: C524.2, L506.1, U501.18 (TRX_SW)
unnamed: C512.1, Y501.3 (OUT)

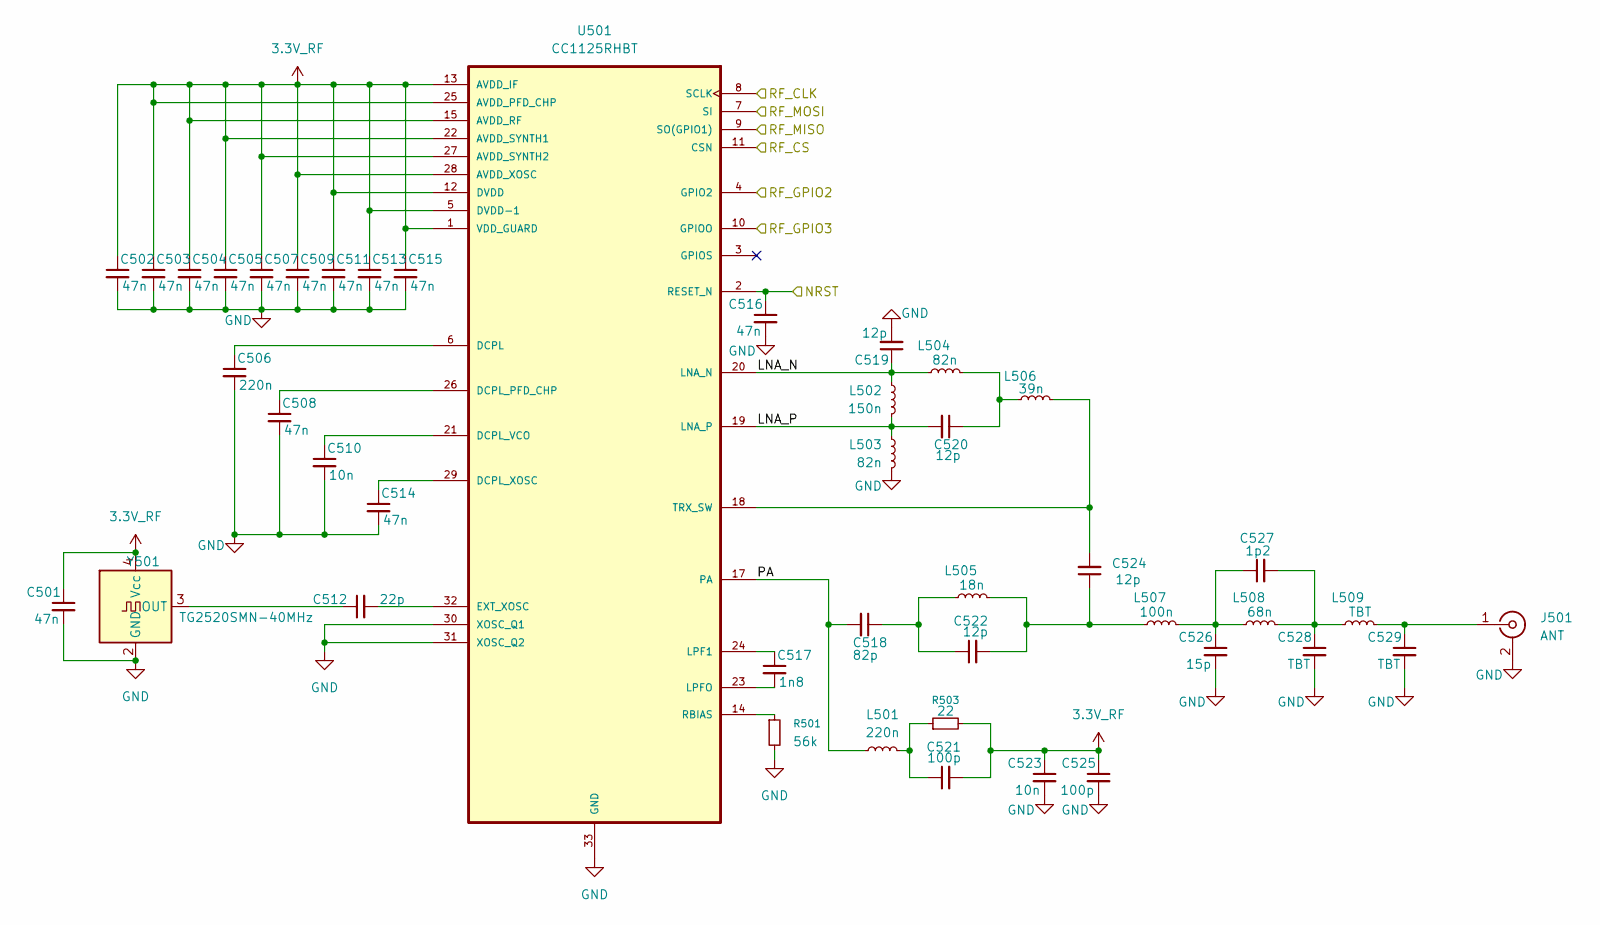
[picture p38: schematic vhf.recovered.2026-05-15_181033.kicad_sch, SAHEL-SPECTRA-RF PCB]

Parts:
C501, C502, C503, C504, C505, C507, C508, C509, C511, C513, C514, C515, C516: 47n; C_0402_1005Metric
C506: 220n; C_0402_1005Metric
C510, C523: 10n; C_0402_1005Metric
C512: 22p; C_0402_1005Metric
C517: 1n8; C_0402_1005Metric
C518: 82p; C_0402_1005Metric
C519, C520, C522, C524: 12p; C_0402_1005Metric
C521, C525: 100p; C_0402_1005Metric
C526: 15p; C_0402_1005Metric
C527: 1p2; C_0402_1005Metric
C528, C529: TBT; C_0402_1005Metric
J501: ANT; U.FL_Hirose_U.FL-R-SMT-1_Vertical
L501: 220n; L_0402_1005Metric
L502: 150n; L_0402_1005Metric
L503, L504: 82n; L_0402_1005Metric
L505: 18n; L_0402_1005Metric
L506: 39n; L_0402_1005Metric
L507: 100n; L_0402_1005Metric
L508: 68n; L_0402_1005Metric
L509: TBT; L_0402_1005Metric
R501: 56k; R_0402_1005Metric
R503: 22; R_0402_1005Metric
U501: CC1125RHBT; QFN-32-1EP_5x5mm_P0.5mm_EP3.45x3.45mm
Y501: TG2520SMN-40MHz; Crystal_SMD_WE_CFPX-218-4Pin_2.5x2.0mm

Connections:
3.3V_RF: C501.1, C502.1, C503.1, C504.1, C505.1, C507.1, C509.1, C511.1, C513.1, C515.1, C521.2, C523.1, C525.1, R503.2, U501.1 (VDD_GUARD), U501.5 (DVDD-1), U501.12 (DVDD), U501.13 (AVDD_IF), U501.15 (AVDD_RF), U501.22 (AVDD_SYNTH1), U501.25 (AVDD_PFD_CHP), U501.27 (AVDD_SYNTH2), U501.28 (AVDD_XOSC), Y501.4 (Vcc); also elsewhere on the board
/MCU/NRST: C516.1, U501.2 (RESET_N); also elsewhere on the board
/MCU/PB10: U501.4 (GPIO2); also elsewhere on the board
/MCU/PE15: U501.10 (GPIOO); also elsewhere on the board
/MCU/SPI4_MISO: U501.9 (SO(GPIO1)); also elsewhere on the board
/MCU/SPI4_MOSI: U501.7 (SI); also elsewhere on the board
/MCU/SPI4_NSS: U501.11 (CSN); also elsewhere on the board
/MCU/SPI4_SCK: U501.8 (SCLK); also elsewhere on the board
/VHF RF/LNA_N: C519.1, L502.2, L504.2, U501.20 (LNA_N)
/VHF RF/LNA_P: C520.2, L502.1, L503.2, U501.19 (LNA_P)
/VHF RF/PA: C518.2, L501.1, U501.17 (PA)
GND: C501.2, C502.2, C503.2, C504.2, C505.2, C506.2, C507.2, C508.2, C509.2, C510.2, C511.2, C513.2, C514.2, C515.2, C516.2, C519.2, C523.2, C525.2, C526.2, C528.2, C529.2, J501.2 (Ext), L503.1, R501.2, U501.30 (XOSC_Q1), U501.31 (XOSC_Q2), U501.33 (GND), Y501.2 (GND); also elsewhere on the board
unnamed: C518.1, C522.1, L505.2
unnamed: C520.1, L504.1, L506.2
unnamed: C521.1, L501.2, R503.1
unnamed: C522.2, C524.1, L505.1, L507.2
unnamed: C526.1, C527.1, L507.1, L508.2
unnamed: C527.2, C528.1, L508.1, L509.2
unnamed: C529.1, J501.1 (In), L509.1
unnamed: C506.1, U501.6 (DCPL)
unnamed: C508.1, U501.26 (DCPL_PFD_CHP)
unnamed: C510.1, U501.21 (DCPL_VCO)
unnamed: C514.1, U501.29 (DCPL_XOSC)
unnamed: C512.2, U501.32 (EXT_XOSC)
unnamed: C517.1, U501.24 (LPF1)
unnamed: C517.2, U501.23 (LPFO)
unnamed: R501.1, U501.14 (RBIAS)
unnamed: C524.2, L506.1, U501.18 (TRX_SW)
unnamed: C512.1, Y501.3 (OUT)

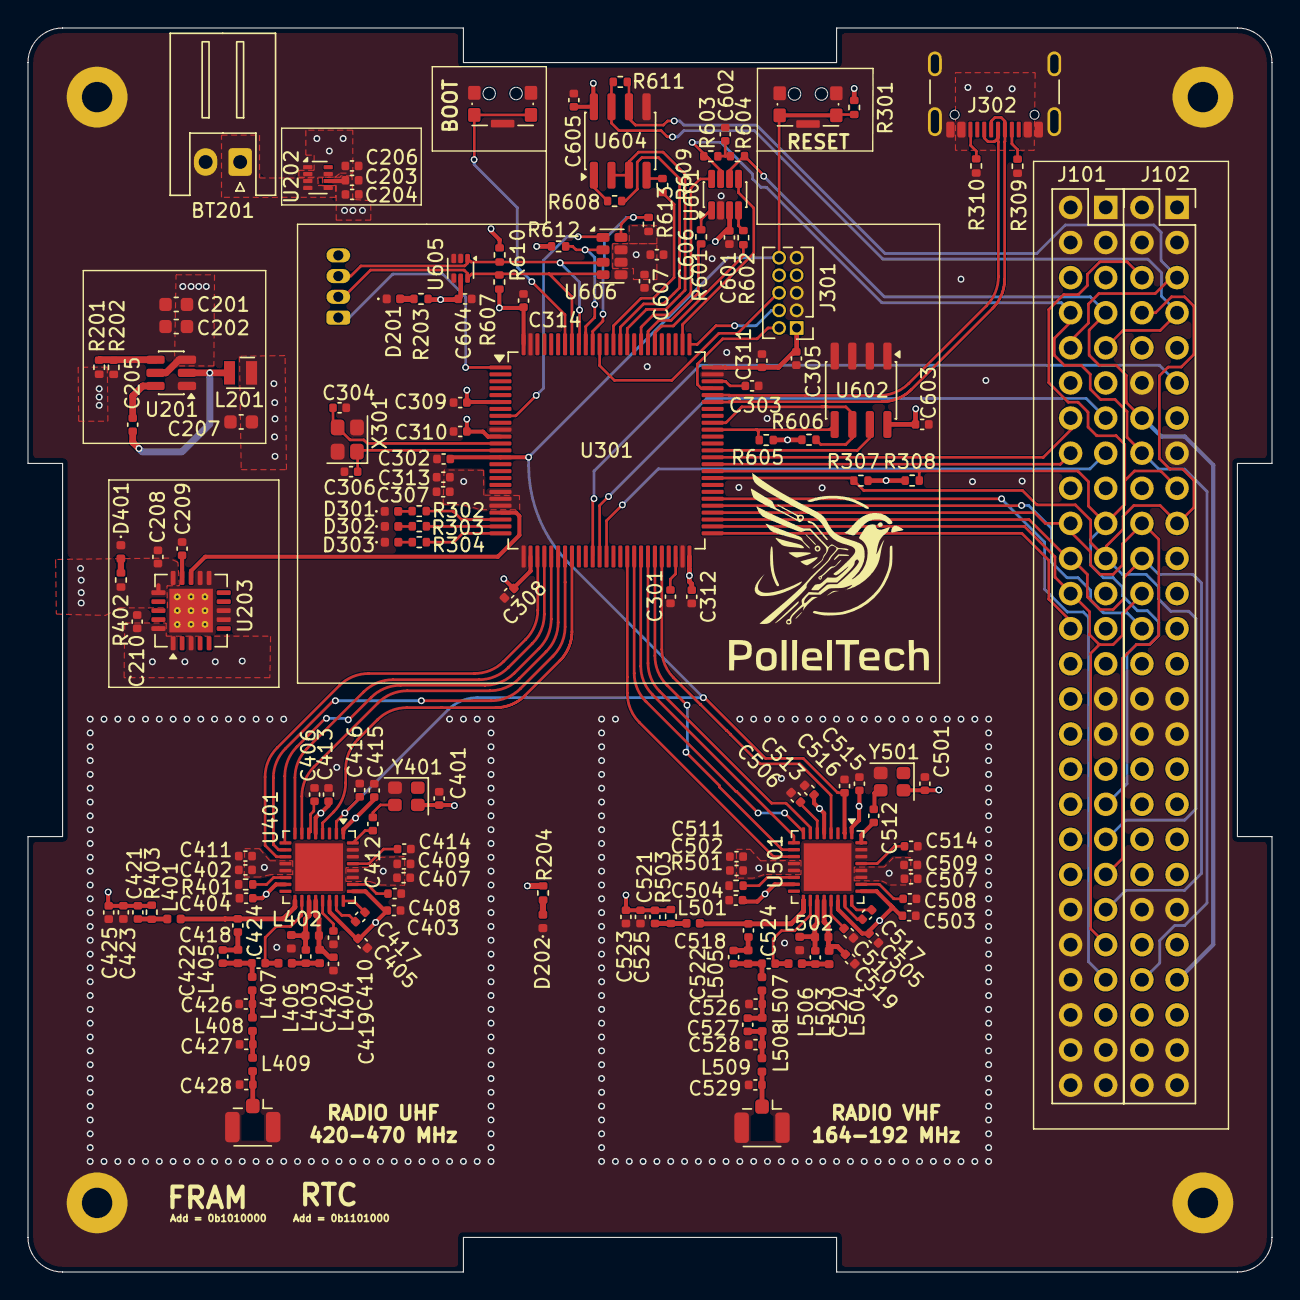
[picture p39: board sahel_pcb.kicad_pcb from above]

Board: 4 copper layers, 90.0 x 90.0 mm, 171 parts (1 on the bottom side), 123 nets.

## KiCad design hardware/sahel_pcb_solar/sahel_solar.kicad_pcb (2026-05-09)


Board: 2 copper layers, 90.0 x 90.0 mm, 58 parts (0 on the bottom side), 34 nets.

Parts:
C201: 2.2u; C_0603_1608Metric
C202, C203, C204, C205, C206, C207, C302, C303, C305: 0.1u; C_0402_1005Metric
C208: 22p; C_0402_1005Metric
C209, C210: 10u; C_0603_1608Metric
C301: 10n; C_0402_1005Metric
C304: 10u; C_0402_1005Metric
C306, C307, C308: 1u; C_0402_1005Metric
D101, D102, D103: SS110; D_SMA
D201: PDS3100; D_PowerDI-5
D202: LED_S1; LED_0402_1005Metric
D203: LED_S2; LED_0402_1005Metric
D204: BAT54; SOT-23
H301, H302, H303, H304: MountingHole_Pad; MountingHole_2.5mm_Pad
J101, J102: Conn_02x26_Odd_Even; PinSocket_2x26_P2.54mm_Vertical
J103: charge; JST_PH_S2B-PH-K_1x02_P2.00mm_Horizontal
L201: 4.7u; L_Vishay_IHLP-2525
Q201, Q202: SiS454DN; Vishay_PowerPAK_1212-8_Single
R201: 2; R_0603_1608Metric
R202: 650k; R_0402_1005Metric
R203, R211: 100k; R_0402_1005Metric
R204: 9.31k; R_0402_1005Metric
R205: 430k; R_0402_1005Metric
R206: 10; R_0603_1608Metric
R207, R208: 10k; R_0402_1005Metric
R209, R301: 10m; R_1206_3216Metric
R210: 290k; R_0402_1005Metric
SC101, SC102, SC103, SC104, SC105, SC106: Solar_Cell; JST_PH_S2B-PH-K_1x02_P2.00mm_Horizontal
TH201: NTC; R_0402_1005Metric
U201: BQ24650; Texas_RVA_VQFN-16-1EP_3.5x3.5mm_P0.5mm_EP2.14x2.14mm_Therma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
U301: INA219AxDCN; SOT-23-8
U302: LSM9DS1; LGA-24L_3x3.5mm_P0.43mm
U303: LPS22HH; ST_HLGA-10_2x2mm_P0.5mm_LayoutBorder3x2y

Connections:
+3.3V: C302.1, C304.1, C305.1, C306.1, C307.1, C308.1, J101.5, J101.6, J101.11, J101.12, J101.17, J101.18, J101.23, J101.27, J101.28, J101.30, J101.33, J101.40, J101.47, J102.9, J102.10, J102.18, J102.21, J102.23, J102.25, J102.27, J102.28, J102.37, J102.38, J102.47, J102.48, U301.4 (VS), U302.1 (VDDIO), U302.3 (VDDIO), U302.5 (SDO_A/G), U302.6 (SDO_M), U302.7 (CS_A/G), U302.8 (CS_M), U302.13 (DEN_A/G), U302.22 (VDD), U302.23 (VDD), U303.1 (Vdd_IO), U303.5 (SA0), U303.6 (~CS), U303.10 (VDD)
/BUS_SCL: J101.21, U301.5 (SCL), U302.2 (SCL/SPC), U303.2 (SCL)
/BUS_SDA: J101.19, U301.6 (SDA), U301.7 (A0), U302.4 (SDA/SDI/SDO), U303.4 (SDA)
/CHARGER/LODRV: Q202.4 (G), U201.13 (LODRV)
/CHARGER/Pack+: C207.2, C208.2, C209.2, C210.2, J103.1, R209.2, R210.1, U201.9 (SRN)
/CHARGER/TS: R204.2, R205.1, TH201.1, U201.4 (TS)
/CHARGER/VFB: C208.1, R210.2, R211.1, U201.8 (VFB)
/DRDY_INT_B: J102.11, U303.7 (INT_DRDY)
/DRDY_M: J101.13, U302.9 (DRDY_M)
/INT_A/G: J101.15, U302.11 (INT1_A/G)
/SOLAR+: D101.1 (K), D102.1 (K), D103.1 (K), D201.2 (A), R201.2, R202.1, R207.2, R208.2, R301.2, U301.1 (IN+)
GND: C201.1, C202.1, C203.1, C204.1, C206.1, C209.1, C210.1, C301.2, C302.2, C303.2, C304.2, C305.2, C306.2, C307.2, C308.2, H301.1 (1_1), H302.1 (1_1), H303.1 (1_1), H304.1 (1_1), J101.1, J101.2, J101.3, J101.4, J101.29, J101.31, J101.42, J101.44, J101.46, J101.48, J101.49, J101.50, J101.51, J101.52, J102.1, J102.2, J102.3, J102.4, J102.12, J102.15, J102.29, J102.30, J102.31, J102.32, J102.41, J102.42, J102.49, J102.50, J102.51, J102.52, J103.2, Q202.1 (S), Q202.2 (S), Q202.3 (S), R203.2, R205.2, R211.2, R301.1, SC101.2 (-), SC102.2 (-), SC103.2 (-), TH201.2, U201.11 (GND), U201.17 (GND), U301.2 (IN-), U301.3 (GND), U301.8 (A1), U302.14 (RES), U302.15 (RES), U302.16 (RES), U302.17 (RES), U302.18 (RES), U302.19 (GND), U302.20 (GND), U303.3 (GND), U303.8 (GND), U303.9 (GND)
unnamed: C201.2, R201.1
unnamed: D101.2 (A), SC104.1 (+)
unnamed: D102.2 (A), SC105.1 (+)
unnamed: D103.2 (A), SC106.1 (+)
unnamed: C206.2, D201.1 (K), Q201.5 (D), R206.1
unnamed: D202.2 (A), R207.1
unnamed: D202.1 (K), U201.3 (STAT1)
unnamed: D203.2 (A), R208.1
unnamed: D203.1 (K), U201.5 (STAT2)
unnamed: C204.2, D204.1 (A), U201.12 (REGN)
unnamed: C205.1, D204.3 (K), U201.16 (BTST)
unnamed: Q201.4 (G), U201.15 (HIDRV)
unnamed: C205.2, L201.1, Q201.1 (S), Q201.2 (S), Q201.3 (S), Q202.5 (D), U201.14 (PH)
unnamed: SC101.1 (+), SC104.2 (-)
unnamed: SC102.1 (+), SC105.2 (-)
unnamed: SC103.1 (+), SC106.2 (-)
unnamed: R202.2, R203.1, U201.2 (MPPSET)
unnamed: C207.1, L201.2, R209.1, U201.10 (SRP)
unnamed: C202.2, R204.1, U201.6 (VREF), U201.7 (TERM_EN)
unnamed: C203.2, R206.2, U201.1 (VCC)
unnamed: C303.1, U302.24 (C1)
unnamed: C301.1, U302.21 (CAP)

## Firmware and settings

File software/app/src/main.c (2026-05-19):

#include <zephyr/kernel.h>
#include <zephyr/device.h>
#include <zephyr/drivers/sensor.h>
#include <zephyr/sys/printk.h>

#include "bq76907.h"

#define BQ76907_NODE DT_INST(0, ti_bq76907)

int main(void)
{
    const struct device *dev = DEVICE_DT_GET(BQ76907_NODE);

    if (!device_is_ready(dev)) {
        printk("BQ76907 not ready\n");
        return -1;
    }

    struct sensor_value val;

    while (1) {

        sensor_sample_fetch(dev);

        sensor_channel_get(dev, SENSOR_CHAN_VOLTAGE, &val);
        printk("Pack voltage: %d.%06d V\n", val.val1, val.val2);

        sensor_channel_get(dev, SENSOR_CHAN_DIE_TEMP, &val);
        printk("Temp: %d C\n", val.val1);

        sensor_channel_get(dev, BQ76907_CHAN_IS_CHARGING, &val);
        printk("Charging: %d\n", val.val1);

        k_sleep(K_SECONDS(2));
    }
}

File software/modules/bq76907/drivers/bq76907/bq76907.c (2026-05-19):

/**
 * @file bq76907.c
 * @brief BQ76907 battery management system driver implementation
 * @details Implements Zephyr sensor API and custom battery management API
 *          including SoC estimation, cell balancing, and protection handling.
 */

#include "bq76907.h"

#define DT_DRV_COMPAT ti_bq76907

LOG_MODULE_REGISTER(bq76907, CONFIG_SENSOR_LOG_LEVEL);


/**
 * @brief Current/voltage safety alarm mapping (SAFETY_ALERT_A / SAFETY_STATUS_A)
 */
static const struct alarm_map alarm_current_voltage_map[] = {
    {0x04, BQ76907_ERROR_OVERCURRENT_CHARGE},
    {0x08, BQ76907_ERROR_OVERCURRENT_DISCHARGE_2},
    {0x10, BQ76907_ERROR_OVERCURRENT_DISCHARGE_1},
    {0x20, BQ76907_ERROR_SHORT_CIRCUIT_DISCHARGE},
    {0x40, BQ76907_ERROR_CELL_UNDERVOLTAGE},
    {0x80, BQ76907_ERROR_CELL_OVERVOLTAGE},
};

/**
 * @brief Temperature safety alarm mapping (SAFETY_ALERT_B / SAFETY_STATUS_B)
 */
static const struct alarm_map alarm_temp_map[] = {
    {0x08, BQ76907_ERROR_INT_OVERTEMPERATURE},
    {0x10, BQ76907_ERROR_UNDERTEMPERATURE_CHARGE},
    {0x20, BQ76907_ERROR_UNDERTEMPERATURE_DISCHARGE},
    {0x40, BQ76907_ERROR_OVERTEMPERATURE_CHARGE},
    {0x80, BQ76907_ERROR_OVERTEMPERATURE_DISCHARGE},
};



/**
 * @brief Read bytes from a register
 * @param dev device structure
 * @param reg Register address
 * @param data Output buffer
 * @param len Number of bytes
 * @return 0 on success, negative error code
 */
 static int bq76907_reg_read(const struct device *dev,
							uint8_t reg,
							uint8_t *data,
							uint8_t len)
{
	const struct bq76907_config *cfg = dev->config;
	return i2c_burst_read_dt(&cfg->i2c, reg, data, len);
}

/**
 * @brief Write bytes to a register
 * @brief Read bytes from a register
 * @param dev device structure
 * @param reg Register address
 * @param data Output buffer
 * @param len Number of bytes
 * @return 0 on success, negative error code
 */
static int bq76907_reg_write(const struct device *dev,
							 uint8_t reg,
							 const uint8_t *data,
							 uint8_t len)
{
	const struct bq76907_config *cfg = dev->config;
	return i2c_burst_write_dt(&cfg->i2c, reg, data, len);
}

/**
 * @brief Write a pass q commande
 * @param dev device structure
 * @param lsb The data LSB
 * @param msb The data MSB
 * @return 0 on success, negative error code
 */

static int bq76907_passq_write(const struct device *dev,
							   uint8_t lsb,
							   uint8_t msb,
							   const uint8_t *data,
							   size_t len)
{
	uint8_t checksum;
	uint8_t length;
	int rc;

	rc = bq76907_reg_write(dev, SUBCMD_LB, &lsb, 1);
	if (rc)
		return rc;
	rc = bq76907_reg_write(dev, SUBCMD_UB, &msb, 1);
	if (rc)
		return rc;

	rc = bq76907_reg_write(dev, PASSQ_START, data, len);
	if (rc)
		return rc;

	checksum = lsb + msb;
	for (size_t i = 0; i < len; i++)
	{
		checksum += data[i];
	}
	checksum = ~checksum;
	rc = bq76907_reg_write(dev, PASSQ_CSUM, &checksum, 1);
	if (rc)
		return rc;

	length = 2 + 2 + len;

	rc = bq76907_reg_write(dev, PASSQ_LEN, &length, 1);
	if (rc)
		return rc;

	return 0;
}

/**
 * @brief Read the battery status
 * @param dev device structure
 * @param status Pointer to store the battery status
 * @return 0 on success, negative error code
 */
static inline int bq76907_read_status(const struct device *dev, uint16_t *status)
{
	return bq76907_reg_read(dev, BATTERY_STATUS, (uint8_t *)status, sizeof(uint16_t));
}

/**
 * @brief Convert the ADC code to temperature
 * @param adcCode ADC code
 * @return Temperature in Celsius
 */
static inline int8_t tsad_to_temperature(uint16_t adcCode)
{
	float vTs = adcCode * 1.8f * 5.0f / 3.0f / 32768.0f; // ≈ 92uV per LSB
	float vRef = 1.8f;
	float rPullup = 20000.0f; // 20kΩ
	float rNTC = rPullup * vTs / (vRef - vTs);

	// Define thermistor parameters (adjust as needed for your NTC)
	float B = 4300.0f;	 // Beta value of thermistor (typical: 3435 or 3950)
	float R0 = 10000.0f; // Resistance at 25°C (10kΩ)
	float T0 = 298.15f;	 // 25°C in Kelvin

	float tempK = 1.0f / ((1.0f / B) * logf(rNTC / R0) + (1.0f / T0));
	float tempC = tempK - 273.15f;
	return (int16_t)roundf(tempC);
}

/**
 * @brief Read the battery temperature
 * @param dev Pointer to the device structure
 * @param temperature Pointer to store the temperature
 * @return 0 on success, negative error code
 */
static inline int bq76907_read_temperature(const struct device *dev, uint8_t *temperature)
{
	uint16_t adc_tmp;
	int rc = bq76907_reg_read(dev, TS_MEASUREMENT, (uint8_t *)&adc_tmp, sizeof(uint16_t));
	if (rc != 0)
		return rc;
	*temperature = tsad_to_temperature(adc_tmp);

	return rc;
}

/**
 * @brief Read all cell voltages
 *
 * @param dev Pointer to the device structure
 * @param cell_voltages Pointer to array of cell voltages
 * @return 0 on success, negative error code
 */
static inline int bq76907_read_cell_voltages(const struct device *dev,
											 uint16_t *cell_voltages)
{
	const struct bq76907_config *cfg = dev->config;
	uint16_t data[cfg->number_cell];
	return bq76907_reg_read(dev,
							CELL_1_VOLTAGE,
							(uint8_t *)data,
							cfg->number_cell * sizeof(uint16_t));
}

/**
 * @brief Read the security keys from the BQ76907
 * @param dev Pointer to the device structure
 * @param key Pointer to store the key
 * @return 0 on success, negative error code
 */
__maybe_unused static int bq76907_read_security_keys(const struct device *dev, uint32_t *key)
{
	uint8_t subcmd[2] = {0x35, 0x00};
	uint8_t keys[4];
	int rc = bq76907_reg_write(dev, SUBCMD_LB, &subcmd[0], 1);
	if (rc != 0)
		return rc;
	rc = bq76907_reg_write(dev, SUBCMD_UB, &subcmd[1], 1);
	if (rc != 0)
		return rc;
	rc = bq76907_reg_read(dev, PASSQ_START, keys, 4);
	if (rc != 0)
		return rc;
	*key = (uint32_t)((uint16_t)keys[0] | ((uint16_t)keys[1] << 8) | (uint16_t)keys[2] | ((uint16_t)keys[3] << 8));
	return rc;
}

/**
 * @brief Read PASSQ accumulated data block
 *
 * @param dev Pointer to device
 * @param subcmd Subcommand (LSB/MSB)
 * @param data Pointer to output buffer (12 bytes)
 *
 * @return 0 on success
 */

static int bq76907_read_passq_block(const struct device *dev,
									uint8_t lsb,
									uint8_t msb,
									uint8_t *data)
{

	int rc = bq76907_reg_write(dev, SUBCMD_LB, &lsb, 1);
	if (rc < 0)
	{
		return rc;
	}

	rc = bq76907_reg_write(dev, SUBCMD_UB, &msb, 1);
	if (rc < 0)
	{
		return rc;
	}

	rc = bq76907_reg_read(dev, PASSQ_START, data, 12);
	if (rc < 0)
	{
		return rc;
	}

	return 0;
}

/**
 * @brief Read accumulated charge
 *
 * @param dev Pointer to device
 * @param charge Pointer to store accumulated charge
 *
 * @return 0 on success
 */
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

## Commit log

2026-05-09 feat(hardware): complete major CubeSat hardware milestone
    Finalize most PCB designs for OBC, radio, power, and solar interfaces
    Complete main mechanical structure design of the CubeSat
    Generate STM32CubeMXIDE software project for STM32H7 platform
    Prepare hardware/software integration baseline for future development
    [BQ76907RGRR.STEP, Cell 18650.STEP, KMS231GPLFS.STEP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]
2026-05-09 docs: advance README documentation
    [Squelette.stl, faces_xy.stl, faces_z.stl]
2026-05-10 docs: advance README documentation
    Remove KiCad project files for sahel_pcb and its subprojects, indicating a clean slate for future development. Mark subprojects as dirty to reflect uncommitted changes.
    [sahel_pcb.kicad_pcb]
2026-05-11 docs: advance README documentation
    Refactor code structure for improved readability and maintainability
    [mcu.kicad_sch, sahel_battery.kicad_pcb, sahel_pcb.kicad_pcb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]
2026-05-16 Add support for Sahel STM32H7B0 board and associated drivers
    - Created device tree source (DTS) file for Sahel STM32H7B0 board with configurations for GPIO, UART, SPI, I2C, CAN, and various sensors.
    - Added YAML configuration for the Sahel STM32H7B0 board, specifying memory and supported features.
    - Introduced default configuration file for the board enabling MPU, stack protection, and GPIO.
    - Implemented CMake and Kconfig files for BQ76907 battery protection module, including driver source and bindings.
    - Added CC1125 radio transceiver module with necessary configurations and driver files.
    - Integrated FM24CL64B I2C FRAM module with complete driver implementation and device tree bindings.
    -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
    [mcu.recovered.2026-05-15_181033.kicad_sch, peripheral.recovered.2026-05-15_181033.kicad_sch, power.recovered.2026-05-15_181033.kicad_sch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]
2026-05-19 Add BQ76907 driver implementation and remove CC1125 module
    - Implemented the BQ76907 driver in `bq76907.h` with necessary data structures, error codes, and sensor channels.
    - Updated device tree bindings for BQ76907 in `ti,bq76907.yml` to include new properties for voltage and current thresholds.
    - Removed the CC1125 module, including its drivers, Kconfig, and device tree bindings, as it is no longer needed.
    - Added a Kconfig dependency for EEPROM in the FM24CL64B driver.
    - Created a new README.md file for documentation purposes.
    [bq76907.c, main.c]
2026-05-19 chore: bump version to v0.0.2
    [sahel_pcb.kicad_pcb, uhf.kicad_sch, vhf.kicad_sch]
